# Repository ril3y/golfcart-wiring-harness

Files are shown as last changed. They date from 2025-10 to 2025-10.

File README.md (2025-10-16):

# Golf Cart Wiring Harness

A KiCad project for designing a golf cart wiring harness with CAN bus communication and microcontroller integration.

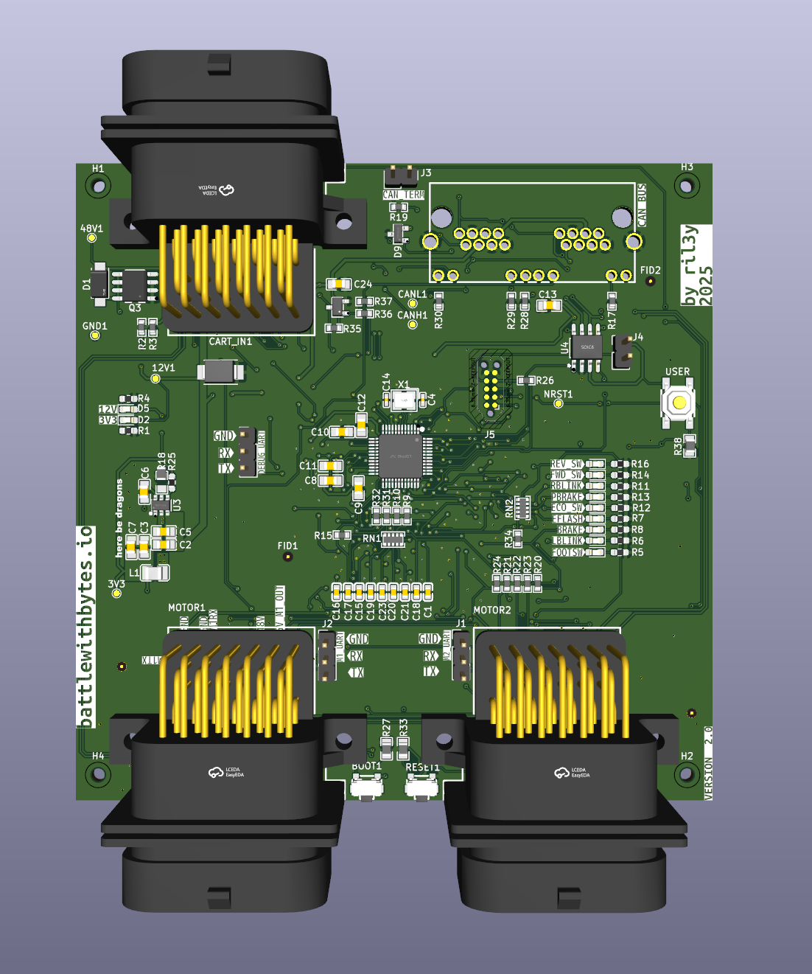
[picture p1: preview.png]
PCB Preview


## Project Overview

This project contains the complete KiCad design files for a golf cart wiring harness system that includes:

- Microcontroller-based control unit
- CAN bus communication interface
- Wire harness connector layouts
- PCB design for control electronics

## Files Structure

```
wire_harness/
├── wire_harness.kicad_pro     # Main project file
├── wire_harness.kicad_sch     # Main schematic
├── mcu-can.kicad_sch          # MCU and CAN interface schematic
├── wire_harness.kicad_pcb     # PCB layout
├── plots/                     # Generated gerber files and plots
└── wire_harness-backups/      # Automatic project backups
```

## Documentation

### Schematic
[View Schematic (PDF)](./schematic.pdf)

### PCB Layout
[View PCB Layout (PDF)](./pcb.pdf)

## Production

- **PCB Order Number**: W2025101705278993
- **PCB Order Date**: October 17, 2025
- **Tag**: `production-W2025101705278993`

## Generated Files

The `plots/` directory contains manufacturing files:
- Gerber files for PCB fabrication
- Drill files for hole placement
- Pick and place files
- Bill of materials

## KiCad Version

This project was created with KiCad 9.0.

## License

This project is open source hardware. Feel free to modify and use for your own golf cart projects.

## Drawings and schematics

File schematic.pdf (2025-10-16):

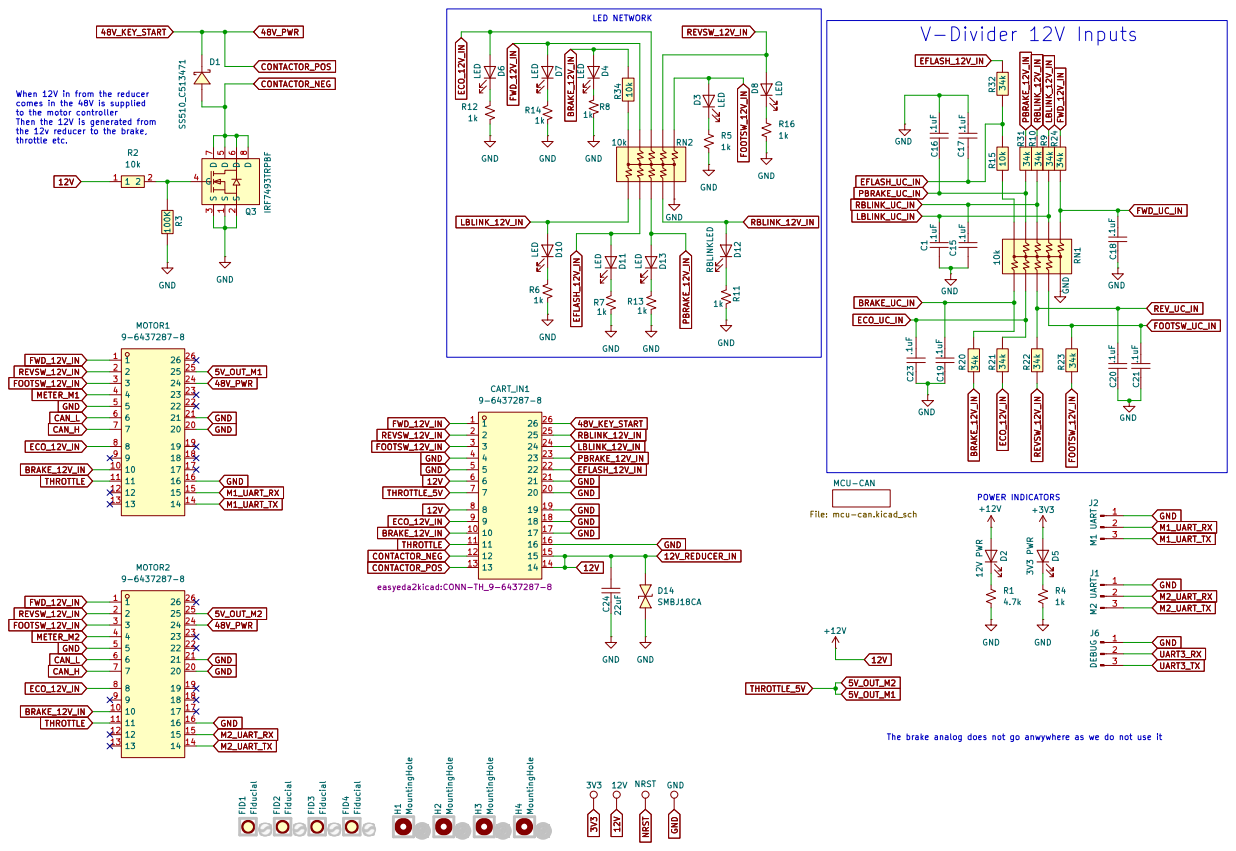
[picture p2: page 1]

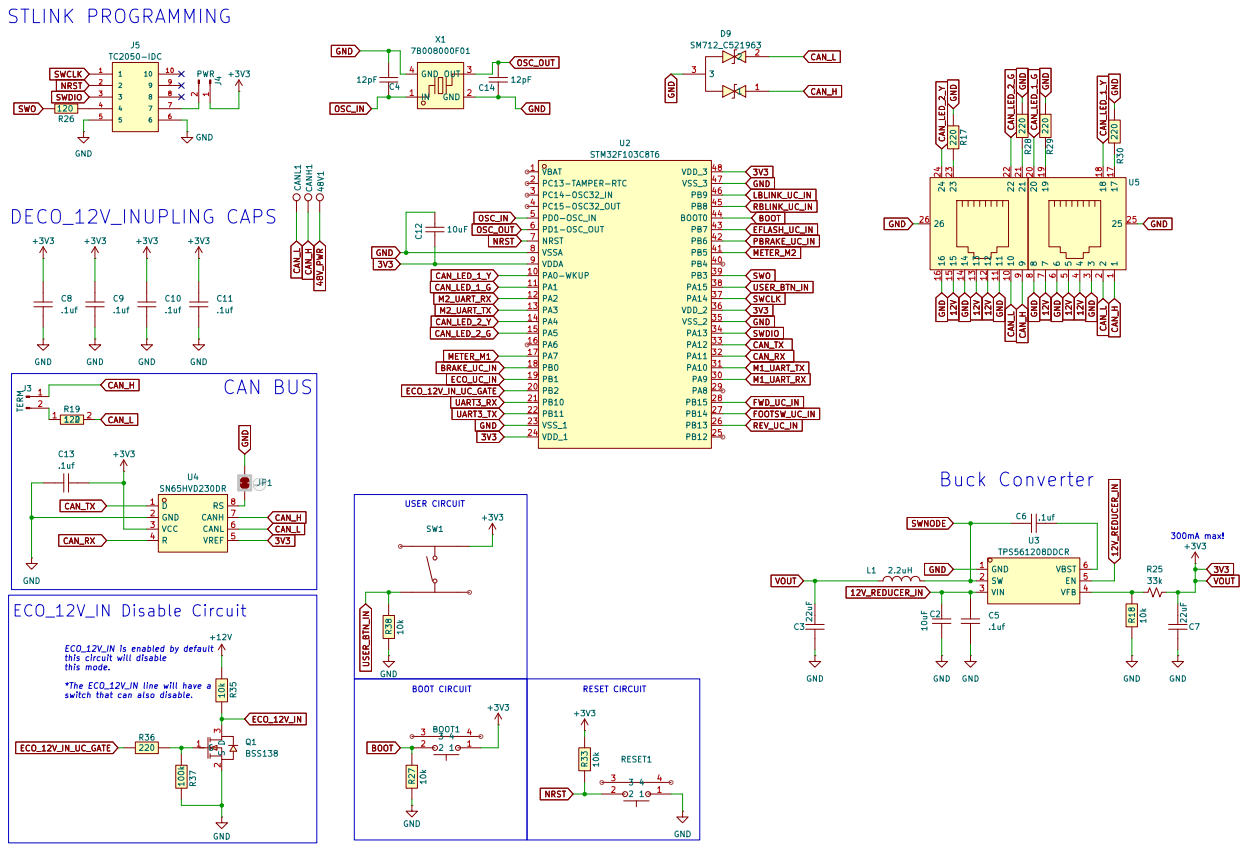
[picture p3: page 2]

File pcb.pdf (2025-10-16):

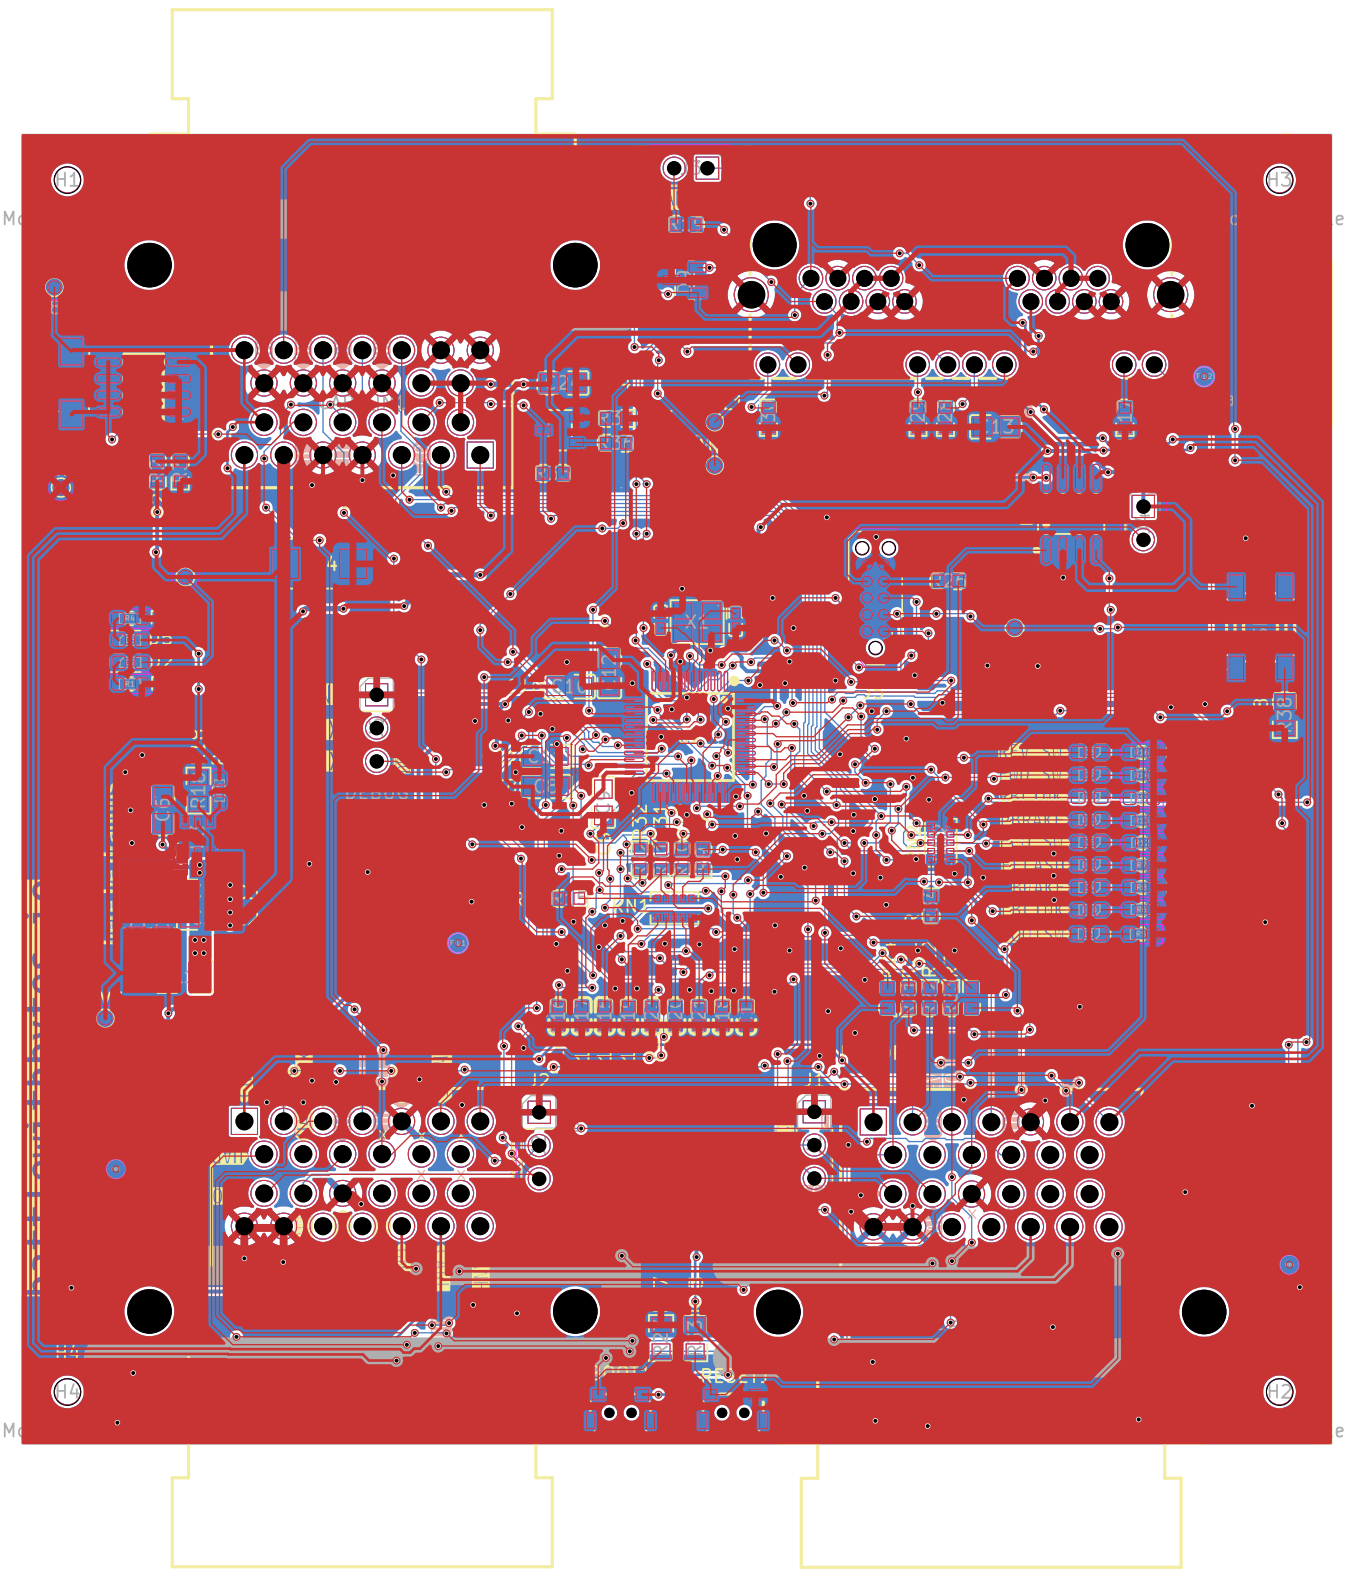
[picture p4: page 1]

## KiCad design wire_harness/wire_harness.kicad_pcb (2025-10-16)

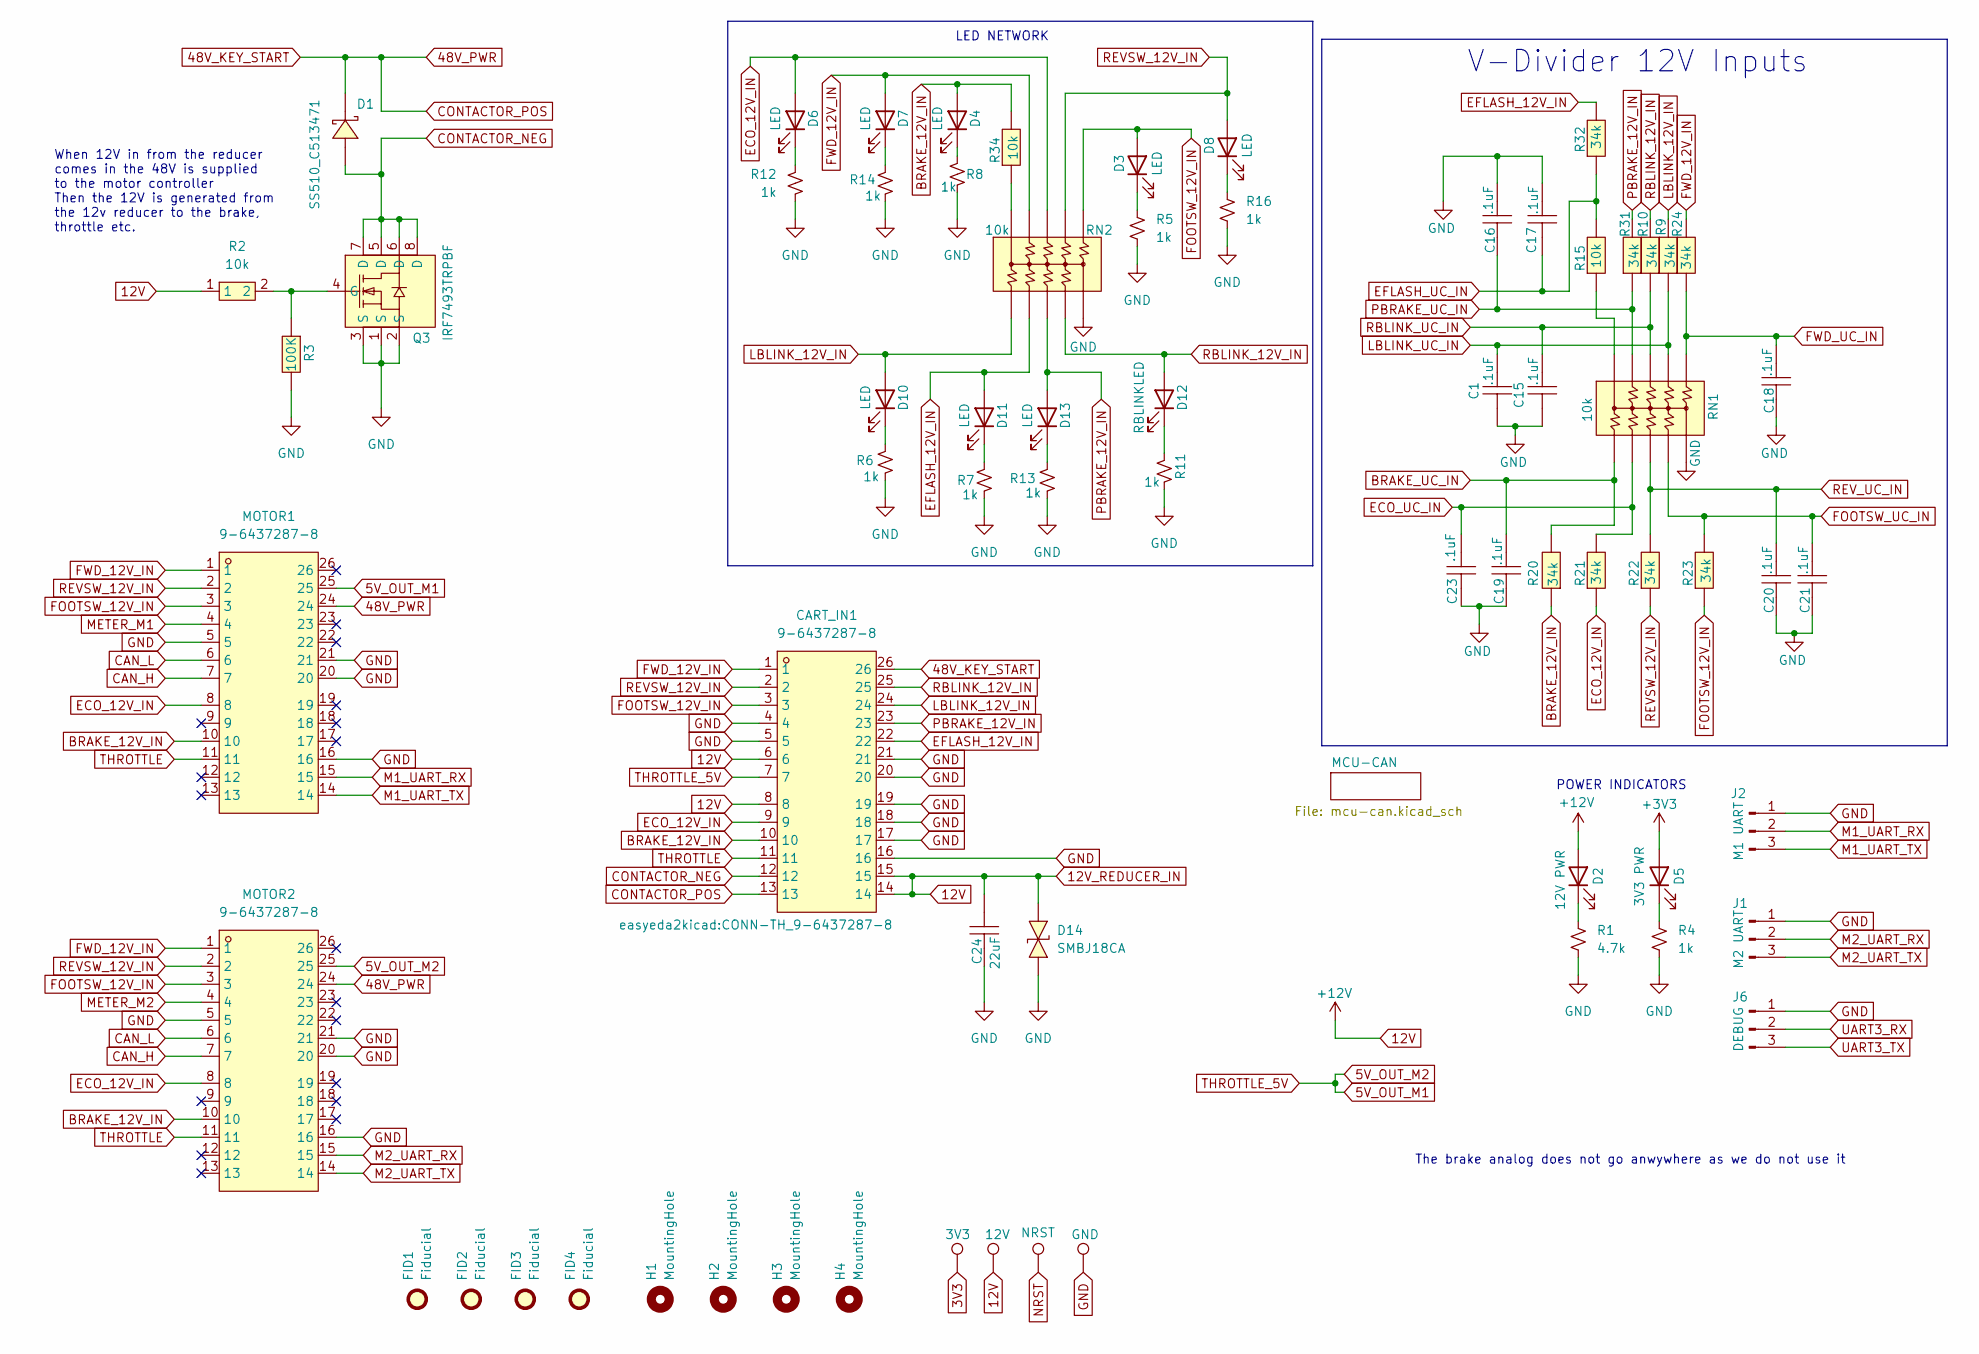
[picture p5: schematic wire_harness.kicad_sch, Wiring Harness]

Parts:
3V3: 3V3; TestPoint_Pad_D1.0mm
12V1: 12V; TestPoint_Pad_D1.0mm
C1, C15, C16, C17, C18, C19, C20, C21, C23: .1uF; C0603; LCSC Part C1591
C24: 22uF; C0805; LCSC Part C602037
CART_IN1: 9-6437287-8; CONN-TH_9-6437287-8; LCSC Part C591814
D1: SS510_C513471; SMA_L4.3-W2.6-LS5.0-RD; LCSC Part C513471
D2: 12V PWR; LED_0603_1608Metric_Pad1.05x0.95mm_HandSolder
D3, D4, D6, D7, D8, D10, D11, D13: LED; LED_0603_1608Metric_Pad1.05x0.95mm_HandSolder
D5: 3V3 PWR; LED_0603_1608Metric_Pad1.05x0.95mm_HandSolder
D12: RBLINKLED; LED_0603_1608Metric_Pad1.05x0.95mm_HandSolder
D14: SMBJ18CA; SMB_L4.6-W3.6-LS5.3-BI; LCSC Part C152103
FID1, FID2, FID3, FID4: Fiducial; Fiducial_0.5mm_Mask1.5mm
GND1: GND; TestPoint_Pad_D1.0mm
H1, H2, H3, H4: MountingHole; MountingHole_2mm
J1: M2 UART; PinHeader_1x03_P2.54mm_Vertical
J2: M1 UART; PinHeader_1x03_P2.54mm_Vertical
J6: DEBUG; PinHeader_1x03_P2.54mm_Vertical
MOTOR1, MOTOR2: 9-6437287-8; CONN-TH_9-6437287-8; LCSC Part C591814
NRST1: NRST; TestPoint_Pad_D1.0mm
Q3: IRF7493TRPBF; SOP-8_L4.9-W3.9-P1.27-LS6.0-BL; LCSC Part C13914
R1: 4.7k; R_0603_1608Metric_Pad0.98x0.95mm_HandSolder
R2, R15, R34: 10k; R0603; LCSC Part C2930027
R3: 100K; R0603; LCSC Part C2907088
R4, R5, R6, R7, R8, R11, R12, R13, R14, R16: 1k; R_0603_1608Metric_Pad0.98x0.95mm_HandSolder
R9, R10, R20, R21, R22, R23, R24, R31, R32: 34k; R0603; LCSC Part C2933202
RN1, RN2: 10k; RES-ARRAY-SMD_1206-L3.2-W1.6-P0.64; LCSC Part C309679

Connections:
3V3: 3V3.1, D5.2 (A); also elsewhere on the board
5V_OUT_M1: CART_IN1.7, MOTOR1.25, MOTOR2.25
12V: 12V1.1, C24.2, CART_IN1.6, CART_IN1.8, CART_IN1.14, CART_IN1.15, D2.2 (A), D14.1 (K), R2.1; also elsewhere on the board
48V_KEY_START: CART_IN1.13, CART_IN1.26, D1.1 (K), MOTOR1.24, MOTOR2.24; also elsewhere on the board
BRAKE_12V_IN: CART_IN1.10, D4.2 (A), MOTOR1.10, MOTOR2.10, R20.1, R34.2
BRAKE_UC_IN: C19.2, R20.2, RN1.1; also elsewhere on the board
CAN_H: MOTOR1.7, MOTOR2.7; also elsewhere on the board
CAN_L: MOTOR1.6, MOTOR2.6; also elsewhere on the board
CONTACTOR_NEG: CART_IN1.12, D1.2 (A), Q3.5 (D), Q3.6 (D), Q3.7 (D), Q3.8 (D)
ECO_12V_IN: CART_IN1.9, D6.2 (A), MOTOR1.8, MOTOR2.8, R21.1, RN2.8; also elsewhere on the board
ECO_UC_IN: C23.2, R21.2, RN1.2; also elsewhere on the board
EFLASH_12V_IN: CART_IN1.22, D11.2 (A), R32.2, RN2.2
EFLASH_UC_IN: C17.1, R15.2, R32.1; also elsewhere on the board
FOOTSW_12V_IN: CART_IN1.3, D3.2 (A), MOTOR1.3, MOTOR2.3, R23.1, RN2.6
FOOTSW_UC_IN: C21.2, R23.2, RN1.4; also elsewhere on the board
FWD_12V_IN: CART_IN1.1, D7.2 (A), MOTOR1.1, MOTOR2.1, R24.2, RN2.9
FWD_UC_IN: C18.2, R24.1, RN1.6; also elsewhere on the board
GND: C1.1, C15.1, C16.2, C17.2, C18.1, C19.1, C20.1, C21.1, C23.1, C24.1, CART_IN1.4, CART_IN1.5, CART_IN1.16, CART_IN1.17, CART_IN1.18, CART_IN1.19, CART_IN1.20, CART_IN1.21, D14.2 (A), GND1.1, J1.1, J2.1, J6.1, MOTOR1.5, MOTOR1.16, MOTOR1.20, MOTOR1.21, MOTOR2.5, MOTOR2.16, MOTOR2.20, MOTOR2.21, Q3.1 (S), Q3.2 (S), Q3.3 (S), R1.2, R3.2, R4.2, R5.2, R6.2, R7.2, R8.2, R11.2, R12.2, R13.2, R14.2, R16.2, RN1.5, RN2.5; also elsewhere on the board
LBLINK_12V_IN: CART_IN1.24, D10.2 (A), R9.2, RN2.1
LBLINK_UC_IN: C1.2, R9.1, RN1.7; also elsewhere on the board
M1_UART_RX: J2.2, MOTOR1.15; also elsewhere on the board
M1_UART_TX: J2.3, MOTOR1.14; also elsewhere on the board
M2_UART_RX: J1.2, MOTOR2.15; also elsewhere on the board
M2_UART_TX: J1.3, MOTOR2.14; also elsewhere on the board
METER_M1: MOTOR1.4; also elsewhere on the board
METER_M2: MOTOR2.4; also elsewhere on the board
NRST: NRST1.1; also elsewhere on the board
unnamed: D2.1 (K), R1.1
unnamed: D3.1 (K), R5.1
unnamed: D4.1 (K), R8.1
unnamed: D5.1 (K), R4.1
unnamed: D6.1 (K), R12.1
unnamed: D7.1 (K), R14.1
unnamed: D8.1 (K), R16.1
unnamed: D10.1 (K), R6.1
unnamed: D11.1 (K), R7.1
unnamed: D12.1 (K), R11.1
unnamed: D13.1 (K), R13.1
unnamed: Q3.4 (G), R2.2, R3.1
unnamed: R15.1, RN1.10
unnamed: R34.1, RN2.10
PBRAKE_12V_IN: CART_IN1.23, D13.2 (A), R31.2, RN2.3
PBRAKE_UC_IN: C16.1, R31.1, RN1.9; also elsewhere on the board
RBLINK_12V_IN: CART_IN1.25, D12.2 (A), R10.2, RN2.4
RBLINK_UC_IN: C15.2, R10.1, RN1.8; also elsewhere on the board
REVSW_12V_IN: CART_IN1.2, D8.2 (A), MOTOR1.2, MOTOR2.2, R22.1, RN2.7
REV_UC_IN: C20.2, R22.2, RN1.3; also elsewhere on the board
THROTTLE: CART_IN1.11, MOTOR1.11, MOTOR2.11
UART3_RX: J6.2; also elsewhere on the board
UART3_TX: J6.3; also elsewhere on the board

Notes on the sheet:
POWER INDICATORS
V-Divider 12V Inputs
When 12V in from the reducer comes in the 48V is supplied to the motor controller Then the 12V is generated from the 12v reducer to the brake, throttle etc.
The brake analog does not go anwywhere as we do not use it
LED NETWORK

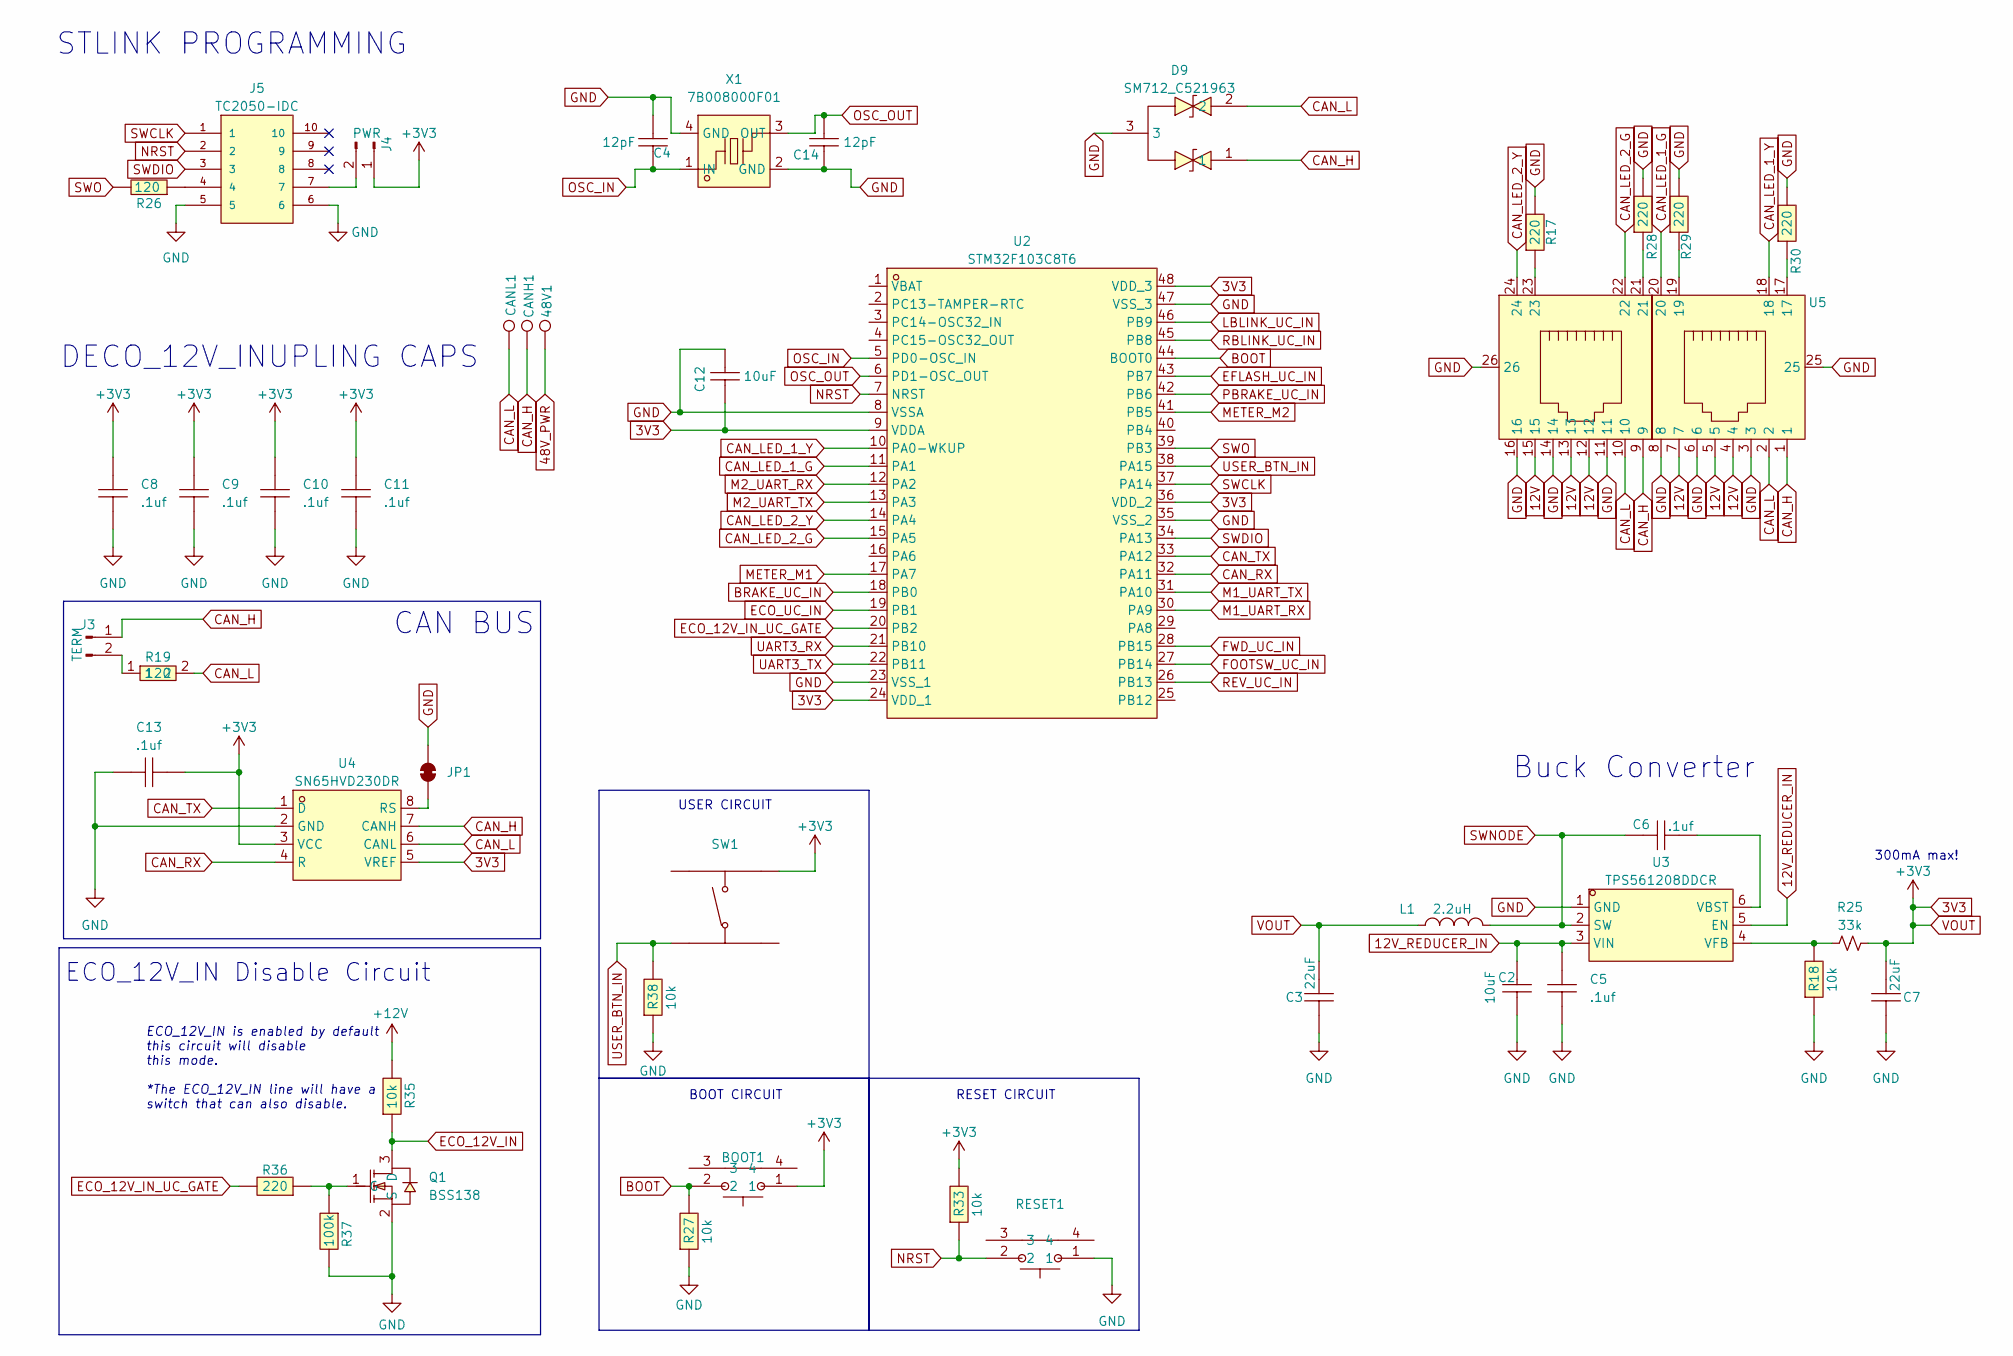
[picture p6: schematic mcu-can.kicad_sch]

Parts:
48V1: 48V; TestPoint_Pad_D1.0mm
BOOT1: 1TS003B-1400-3500A; KEY-SMD_1TS003B; LCSC Part C319392
C2, C12: 10uF; C0805; LCSC Part C1713
C3, C7: 22uF; C0805; LCSC Part C602037
C4, C14: 12pF; C0402; LCSC Part C1547
C5, C6, C8, C9, C10, C11, C13: .1uf; C0805; LCSC Part C6119927
CANH1: CANH; TestPoint_Pad_D1.0mm
CANL1: CANL; TestPoint_Pad_D1.0mm
D9: SM712_C521963; SOT-23-3_L2.9-W1.3-P1.90-LS2.4-BR; LCSC Part C521963
J3: TERM; PinHeader_1x02_P2.54mm_Vertical
J4: PWR; PinHeader_1x02_P2.54mm_Vertical
J5: TC2050-IDC; Tag-Connect_TC2050-IDC-NL_2x05_P1.27mm_Vertical
JP1: SolderJumper_2_Bridged; SolderJumper-2_P1.3mm_Bridged2Bar_Pad1.0x1.5mm
L1: 2.2uH; L1008; LCSC Part C1017131
Q1: BSS138; SOT-23-3_L2.9-W1.6-P1.90-LS2.8-BR; LCSC Part C427380
R17, R28, R29, R30, R36: 220; R0603; LCSC Part C2770951
R18, R27, R33, R38: 10k; R0805; LCSC Part C2930231
R19, R26: 120; R0603; LCSC Part C103256
R25: 33k; R_0603_1608Metric_Pad0.98x0.95mm_HandSolder
R35: 10k; R0603; LCSC Part C2930027
R37: 100k; R0603; LCSC Part C2907088
RESET1: 1TS003B-1400-3500A; KEY-SMD_1TS003B; LCSC Part C319392
SW1: 4*4*1.7; SW-SMD_4P-L5.2-W5.2-P3.70-LS6.5; LCSC Part C10852
U2: STM32F103C8T6; LQFP-48_L7.0-W7.0-P0.50-LS9.0-BL; LCSC Part C8734
U3: TPS561208DDCR; TSOT-23-6_L2.9-W1.6-P0.95-LS2.8-BR; LCSC Part C138335
U4: SN65HVD230DR; SOIC-8_L4.9-W3.9-P1.27-LS6.0-BL; LCSC Part C12084
U5: HC-RJ45-5JA-2-2; RJ45-TH_HCTL_HC-RJ45-5JA-2-2-Y; LCSC Part C3000178
X1: 7B008000F01; CRYSTAL-SMD_4P-L3.2-W2.5-BL; LCSC Part C648984

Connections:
3V3: BOOT1.1, C3.2, C7.2, C8.2, C9.2, C10.2, C11.2, C12.1, C13.1, J4.1, L1.1, R25.2, R33.2, SW1.2, U2.9 (VDDA), U2.24 (VDD_1), U2.36 (VDD_2), U2.48 (VDD_3), U4.3 (VCC), U4.5 (VREF); also elsewhere on the board
12V: C2.2, C5.2, R35.2, U3.3 (VIN), U3.5 (EN), U5.4, U5.5, U5.7, U5.12, U5.13, U5.15; also elsewhere on the board
48V_KEY_START: 48V1.1; also elsewhere on the board
BOOT: BOOT1.2, R27.2, U2.44 (BOOT0)
BRAKE_UC_IN: U2.18 (PB0); also elsewhere on the board
CAN_H: CANH1.1, D9.1, J3.1, U4.7 (CANH), U5.1, U5.9; also elsewhere on the board
CAN_L: CANL1.1, D9.2, R19.2, U4.6 (CANL), U5.2, U5.10; also elsewhere on the board
CAN_LED_1_G: U2.11 (PA1), U5.20
CAN_LED_1_Y: U2.10 (PA0-WKUP), U5.18
CAN_LED_2_G: U2.15 (PA5), U5.22
CAN_LED_2_Y: U2.14 (PA4), U5.24
CAN_RX: U2.32 (PA11), U4.4 (R)
CAN_TX: U2.33 (PA12), U4.1 (D)
ECO_12V_IN: Q1.3 (D), R35.1; also elsewhere on the board
ECO_12V_IN_UC_GATE: R36.2, U2.20 (PB2)
ECO_UC_IN: U2.19 (PB1); also elsewhere on the board
EFLASH_UC_IN: U2.43 (PB7); also elsewhere on the board
FOOTSW_UC_IN: U2.27 (PB14); also elsewhere on the board
FWD_UC_IN: U2.28 (PB15); also elsewhere on the board
GND: C2.1, C3.1, C4.2, C5.1, C7.1, C8.1, C9.1, C10.1, C11.1, C12.2, C13.2, C14.1, D9.3, J5.5, J5.6, JP1.2 (B), Q1.2 (S), R17.2, R18.1, R27.1, R28.2, R29.2, R30.2, R37.2, R38.1, RESET1.1, U2.8 (VSSA), U2.23 (VSS_1), U2.35 (VSS_2), U2.47 (VSS_3), U3.1 (GND), U4.2 (GND), U5.3, U5.6, U5.8, U5.11, U5.14, U5.16, U5.25, U5.26, X1.2 (GND), X1.4 (GND); also elsewhere on the board
LBLINK_UC_IN: U2.46 (PB9); also elsewhere on the board
M1_UART_RX: U2.30 (PA9); also elsewhere on the board
M1_UART_TX: U2.31 (PA10); also elsewhere on the board
M2_UART_RX: U2.12 (PA2); also elsewhere on the board
M2_UART_TX: U2.13 (PA3); also elsewhere on the board
METER_M1: U2.17 (PA7); also elsewhere on the board
METER_M2: U2.41 (PB5); also elsewhere on the board
NRST: J5.2, R33.1, RESET1.2, U2.7 (NRST); also elsewhere on the board
unnamed: J3.2, R19.1
unnamed: J4.2, J5.7
unnamed: J5.4, R26.1
unnamed: JP1.1 (A), U4.8 (RS)
unnamed: Q1.1 (G), R36.1, R37.1
unnamed: R17.1, U5.23
unnamed: R28.1, U5.21
unnamed: R29.1, U5.19
unnamed: R30.1, U5.17
unnamed: C6.1, U3.6 (VBST)
unnamed: R18.2, R25.1, U3.4 (VFB)
OSC_IN: C4.1, U2.5 (PD0-OSC_IN), X1.1 (IN)
OSC_OUT: C14.2, U2.6 (PD1-OSC_OUT), X1.3 (OUT)
PBRAKE_UC_IN: U2.42 (PB6); also elsewhere on the board
RBLINK_UC_IN: U2.45 (PB8); also elsewhere on the board
REV_UC_IN: U2.26 (PB13); also elsewhere on the board
SWCLK: J5.1, U2.37 (PA14)
SWDIO: J5.3, U2.34 (PA13)
SWNODE: C6.2, L1.2, U3.2 (SW)
SWO: R26.2, U2.39 (PB3)
UART3_RX: U2.21 (PB10); also elsewhere on the board
UART3_TX: U2.22 (PB11); also elsewhere on the board
USER_BTN_IN: R38.2, SW1.3, U2.38 (PA15); also elsewhere on the board

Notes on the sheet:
ECO_12V_IN Disable Circuit
BOOT CIRCUIT
STLINK PROGRAMMING
ECO_12V_IN is enabled by default this circuit will disable this mode. *The ECO_12V_IN line will have a switch that can also disable.
CAN BUS
DECO_12V_INUPLING CAPS
Buck Converter
300mA max!
USER CIRCUIT
RESET CIRCUIT

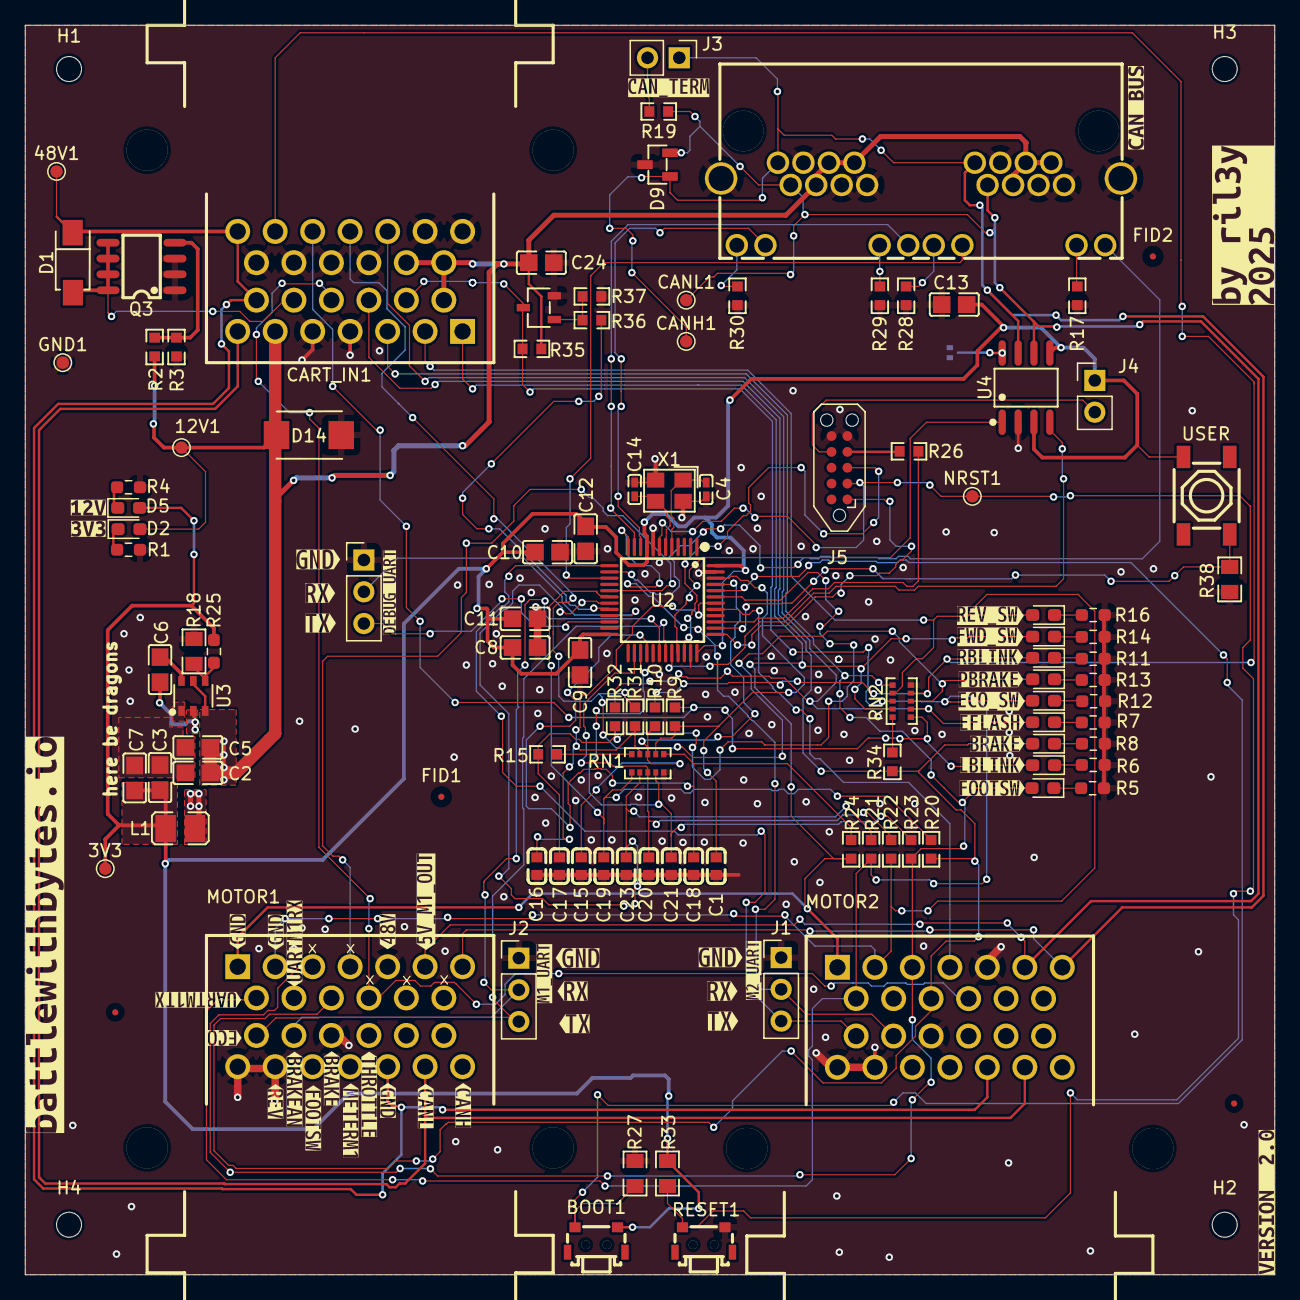
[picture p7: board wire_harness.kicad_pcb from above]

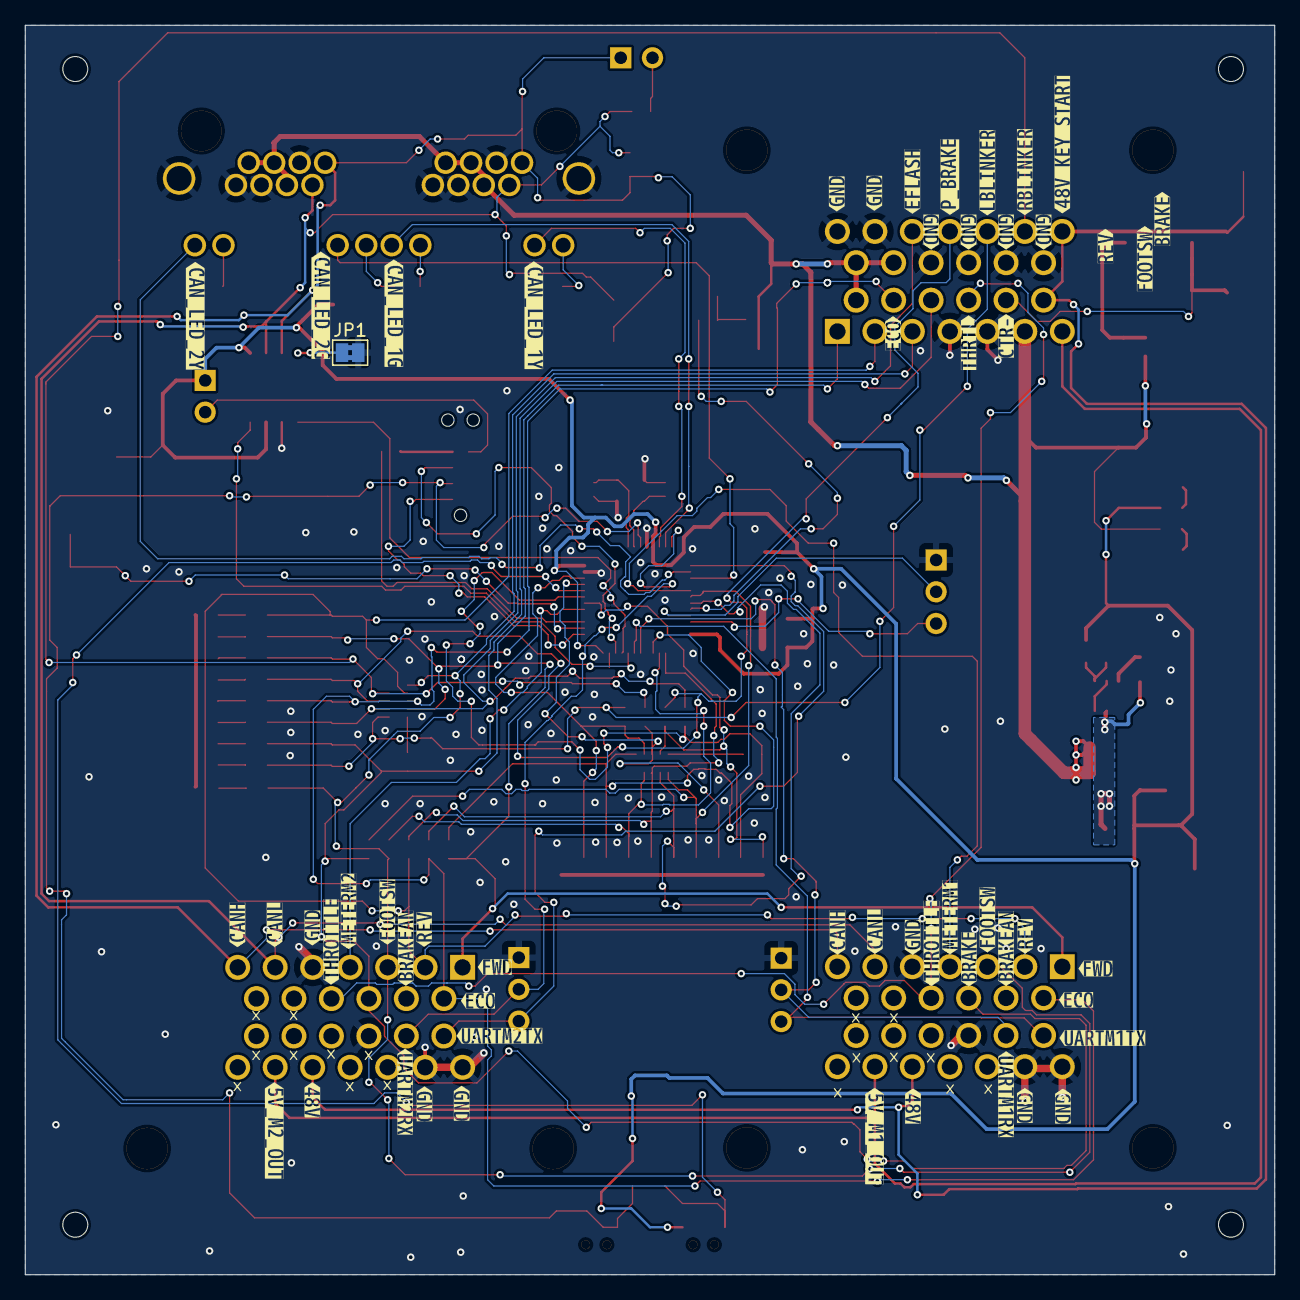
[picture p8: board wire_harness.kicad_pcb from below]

Board: 2 copper layers, 100.0 x 100.0 mm, 211 parts (55 on the bottom side), 76 nets.

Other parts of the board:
USER: 4*4*1.7; SW-SMD_4P-L5.2-W5.2-P3.70-LS6.5
kibuzzard-68F14D91: G***; kibuzzard-68F14D91
kibuzzard-68F14E9F: G***; kibuzzard-68F14E9F
kibuzzard-68F14ED2: G***; kibuzzard-68F14ED2
kibuzzard-68F129BA: G***; kibuzzard-68F129BA
kibuzzard-68F134A4, kibuzzard-68F134A4#2: G***; kibuzzard-68F134A4
kibuzzard-68F134DA: G***; kibuzzard-68F134DA
kibuzzard-68F137E9: G***; kibuzzard-68F137E9
kibuzzard-68F137F1: G***; kibuzzard-68F137F1
kibuzzard-68F137FA: G***; kibuzzard-68F137FA
kibuzzard-68F138FC: G***; kibuzzard-68F138FC
kibuzzard-68F1349C, kibuzzard-68F1349C#2: G***; kibuzzard-68F1349C
kibuzzard-68F1381A: G***; kibuzzard-68F1381A
kibuzzard-68F1394E: G***; kibuzzard-68F1394E
kibuzzard-68F1395A: G***; kibuzzard-68F1395A
kibuzzard-68F13268: G***; kibuzzard-68F13268
kibuzzard-68F13492, kibuzzard-68F13492#2: G***; kibuzzard-68F13492
kibuzzard-68F13943: G***; kibuzzard-68F13943
kibuzzard-68F13965: G***; kibuzzard-68F13965
kibuzzard-685E9542: G***; kibuzzard-685E9542
kibuzzard-685E9548: G***; kibuzzard-685E9548
kibuzzard-685E9594: G***; kibuzzard-685E9594
kibuzzard-6861DCA1: G***; kibuzzard-6861DCA1
kibuzzard-6861DCF7: G***; kibuzzard-6861DCF7
kibuzzard-6876FB65: G***; kibuzzard-6876FB65
kibuzzard-68782A08, kibuzzard-68782A08#2, kibuzzard-68782A08#3: G***; kibuzzard-68782A08
kibuzzard-68782ACC, kibuzzard-68782ACC#2, kibuzzard-68782ACC#3: G***; kibuzzard-68782ACC
kibuzzard-68782B3B: G***; kibuzzard-68782B3B
kibuzzard-68782B6B, kibuzzard-68782B6B#2: G***; kibuzzard-68782B6B
kibuzzard-68782B7F, kibuzzard-68782B7F#2, kibuzzard-68782B7F#3: G***; kibuzzard-68782B7F
kibuzzard-68782B8A, kibuzzard-68782B8A#2, kibuzzard-68782B8A#3: G***; kibuzzard-68782B8A
kibuzzard-68782B9B, kibuzzard-68782B9B#2: G***; kibuzzard-68782B9B
kibuzzard-68782B26, kibuzzard-68782B26#2, kibuzzard-68782B26#3: G***; kibuzzard-68782B26
kibuzzard-68782B56, kibuzzard-68782B56#2: G***; kibuzzard-68782B56
kibuzzard-68782BAF: G***; kibuzzard-68782BAF
kibuzzard-68782BD3, kibuzzard-68782BD3#2: G***; kibuzzard-68782BD3
kibuzzard-68782BE1, kibuzzard-68782BE1#2, kibuzzard-68782BE1#3: G***; kibuzzard-68782BE1
kibuzzard-68782BF2, kibuzzard-68782BF2#2, kibuzzard-68782BF2#3: G***; kibuzzard-68782BF2
kibuzzard-68782C3E: G***; kibuzzard-68782C3E
kibuzzard-68782C4C, kibuzzard-68782C4C#2: G***; kibuzzard-68782C4C
kibuzzard-68782C17, kibuzzard-68782C17#2: G***; kibuzzard-68782C17
kibuzzard-68782C24: G***; kibuzzard-68782C24
kibuzzard-68782C33, kibuzzard-68782C33#2, kibuzzard-68782C33#3: G***; kibuzzard-68782C33
kibuzzard-68782F7C: G***; kibuzzard-68782F7C
kibuzzard-68805E5A: G***; kibuzzard-68805E5A
kibuzzard-68805E6D: G***; kibuzzard-68805E6D
kibuzzard-68805E53: G***; kibuzzard-68805E53
kibuzzard-68805E74: G***; kibuzzard-68805E74
kibuzzard-68805F7D: G***; kibuzzard-68805F7D
kibuzzard-68805F52: G***; kibuzzard-68805F52
kibuzzard-68805F93: G***; kibuzzard-68805F93
kibuzzard-68805FB4: G***; kibuzzard-68805FB4
kibuzzard-687828AA, kibuzzard-687828AA#2, kibuzzard-687828AA#3, kibuzzard-687828AA#4: G***; kibuzzard-687828AA
kibuzzard-688044A1: G***; kibuzzard-688044A1
kibuzzard-6878289E: G***; kibuzzard-6878289E
kibuzzard-68782841, kibuzzard-68782841#2: G***; kibuzzard-68782841
kibuzzard-68782877: G***; kibuzzard-68782877
kibuzzard-68782896: G***; kibuzzard-68782896
kibuzzard-68782918, kibuzzard-68782918#2, kibuzzard-68782918#3, kibuzzard-68782918#4, kibuzzard-68782918#5, kibuzzard-68782918#6, kibuzzard-68782918#7, kibuzzard-68782918#8, kibuzzard-68782918#9: G***; kibuzzard-68782918
kibuzzard-68782976: G***; kibuzzard-68782976
kibuzzard-68782984: G***; kibuzzard-68782984
kibuzzard-68782990: G***; kibuzzard-68782990

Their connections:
3V3: USER.2; also elsewhere on the board
USER_BTN_IN: USER.3; also elsewhere on the board

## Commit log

2025-06-30 Initial commit: Golf cart wiring harness KiCad project
    [mcu-can.kicad_sch, wire_harness.kicad_pcb, wire_harness.kicad_sch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]
2025-06-30 Add README.md with project documentation and PDF schematics
2025-07-26 v2 updates: Modified KiCad schematics and PCB layout, updated backups
    [mcu-can.kicad_sch, wire_harness.kicad_pcb, wire_harness.kicad_sch]
2025-07-26 Minor updates: permissions and schematic labels
    [wire_harness.kicad_sch]
2025-07-26 Update KiCad files and backups
    [wire_harness.kicad_pcb, wire_harness.kicad_sch]
2025-10-16 Production release: Finalized wire harness design for PCB order W2025101705278993
    This commit includes the production-ready hardware design with updated schematics, PCB layout, manufacturing plots, BOM generation, and interactive BOM. Old backup files have been cleaned up and replaced with current design iterations.
    Changes:
    - Updated main schematic and MCU-CAN sub-schematic with final routing
    - Finalized PCB layout with all components and traces
    - Generated production plots and Gerber job files
    - Added Bill of Materials (BOM) and interactive BOM (iBOM) for manufacturing
    - Cleaned up outdated backup files from July-August
    - Retained current backup history from recent design iterations
    Co-A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
    [mcu-can.kicad_sch, wire_harness.kicad_pcb, wire_harness.kicad_sch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]
2025-10-16 Production release: Finalized wire harness design for PCB order W2025101705278993
    This commit includes the complete production-ready hardware design with updated schematics,
    PCB layout, manufacturing plots, BOM generation, interactive BOM, and updated documentation.
    - Updated main schematic with final component placements and routing
    - Updated MCU-CAN sub-schematic
    - Regenerated production PDFs (schematic.pdf and pcb.pdf)
    - Added PCB preview image to documentation
    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
    [wire_harness.kicad_sch]
